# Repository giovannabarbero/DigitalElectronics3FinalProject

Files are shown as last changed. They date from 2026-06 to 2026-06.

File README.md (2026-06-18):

# Sistema de Medición de Nivel Sonoro - Sonómetro
> **Asignatura:** Electrónica Digital III - Universidad Nacional de Córdoba

> **Integrantes:**
> * Thomas von Büren - 43136697
> * Giovanna Luz Barbero - 46509956

> **Profesor:** Ing Marcos Blasco

---

## 🚀 1. Descripción General del Proyecto
Se toman mediciones del sonido ambiente mediante un micrófono, se procesa la información mediante estándares industriales aplicados a decibelímetros sonoros regulados, y se devuelve un valor en decibelios para ser expuesto mediante actuadores, indicadores visuales, e interfaces de comunicación. Posee un modo de auto-calibración.

### 🎯 Alcances del Proyecto 
* **El sistema SÍ es capaz de:** 
    * Adquirir información sonora ambiente en tiempo real.
    * Realizar cálculos de ponderación de curvas reguladas IEC 61672-1 y ANSI S1.43 sobre los datos obtenidos.
    * Calcular el valor en decibelios del sonido.
    * Mostrar valor y curva seleccionada en displays.
    * Mostrar el nivel en un Vu-Meter analógico y una tira ARGB LED NeoPixel.
    * Cambiar tau de adquisición y curva de ponderación *on the go*.
    * Inicializar modo de calibración para chequear correcta interpretación de valores ingresados.
    * Enviar String de información y recibir comandos mediante UART.
* **El sistema NO incluye (Fuera de alcance):** 
    * Almacenamiento local.
    * Portabilidad energética.
    * Conectividad por WiFi/Bluetooth/Ethernet.
    * Rigurosidad homologada ni certificada.

### ⏩ Posibles Etapas Siguientes 
* Migrar el circuito de protoboard a un circuito impreso (PCB) diseñado bajo normas de compatibilidad electromagnética (EMC).
* Implementar componente portable con batería para mejorar portabilidad.
* Emplear componentes especializados de mejor calidad y ad hoc al dispositivo

---

## 📐 2. Arquitectura del Sistema: Hardware y Software

### 🔌 Hardware & Interconexión
* **Diagrama de Bloques:**
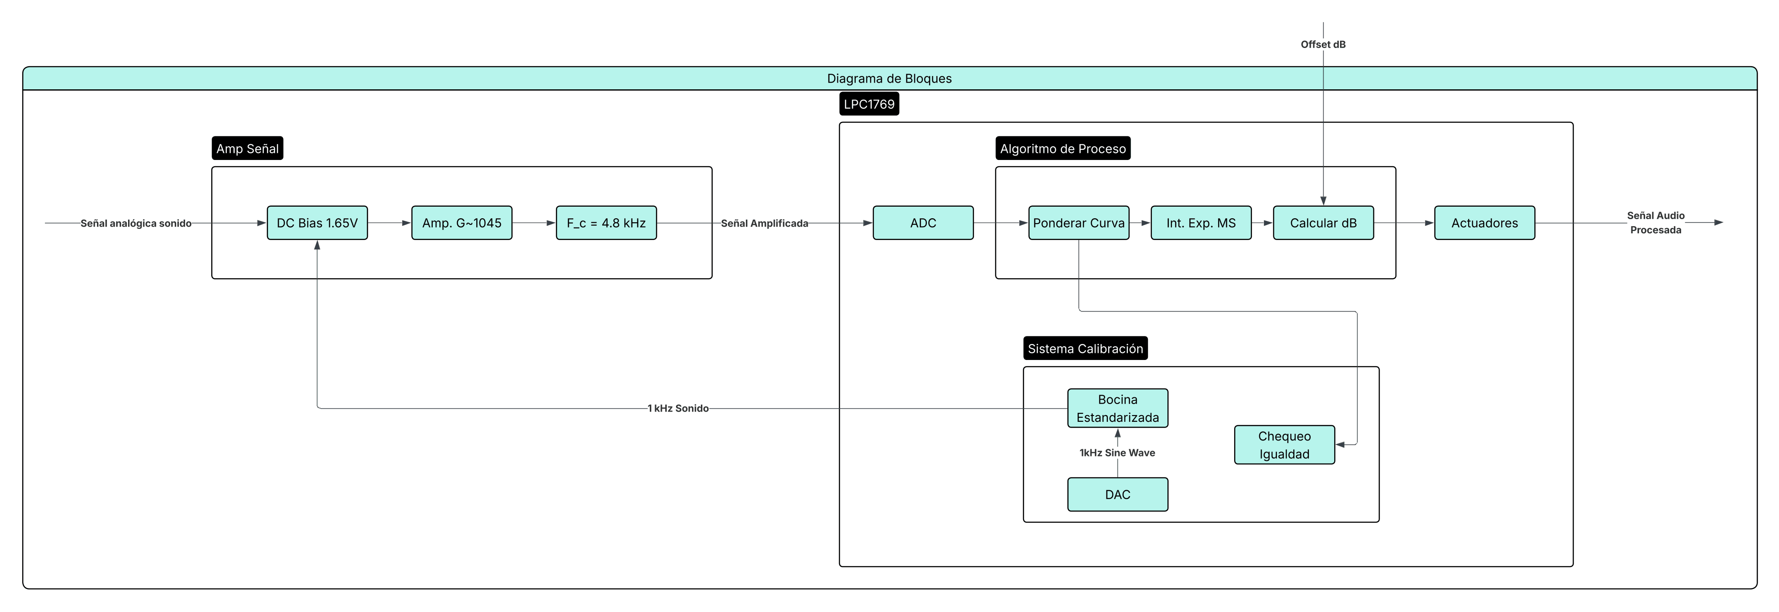
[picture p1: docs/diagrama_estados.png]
Máquina de Estados
  
* **Esquemático del Circuito:** 
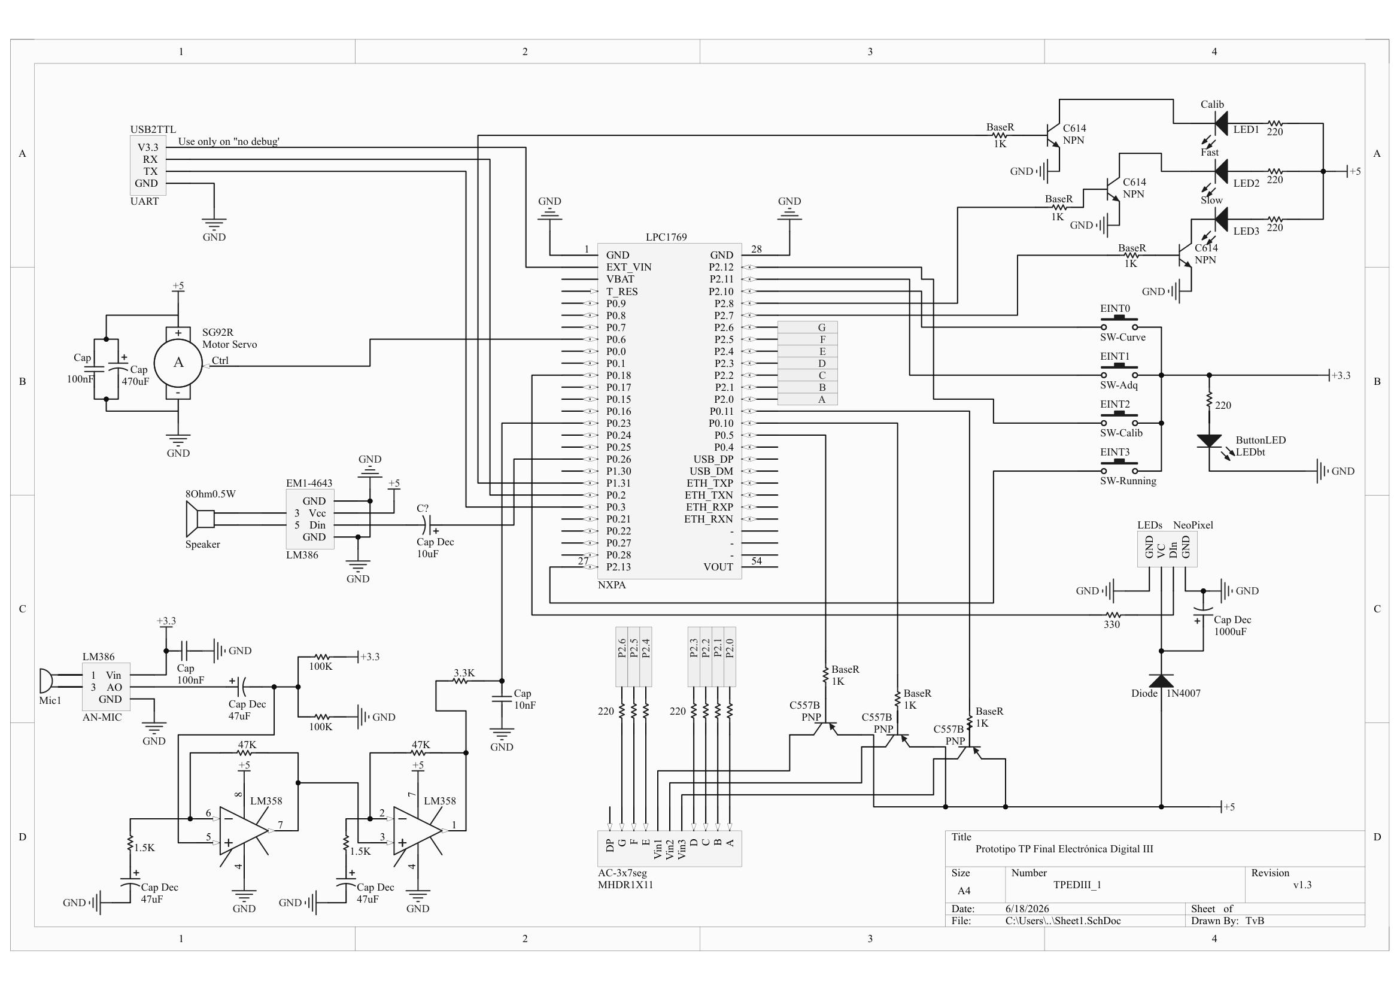
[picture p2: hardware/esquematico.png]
Esquemático Completo
  
* **Descripción del Circuito y Consideraciones de Diseño:** 
    * Pines de displays...
    * Diodo en Neopixel...
    * Decouple en bocina...
    * Botones y Led...
    * Decouple en Servo...
    * Amplificador de Micrófono:
        * Etapa bias y decouple... 
        * Etapa amp...
        * Etapa filtro...

### 💻 Arquitectura de Software (Firmware)
* **Diagrama de Flujo o Máquina de Estados:** 
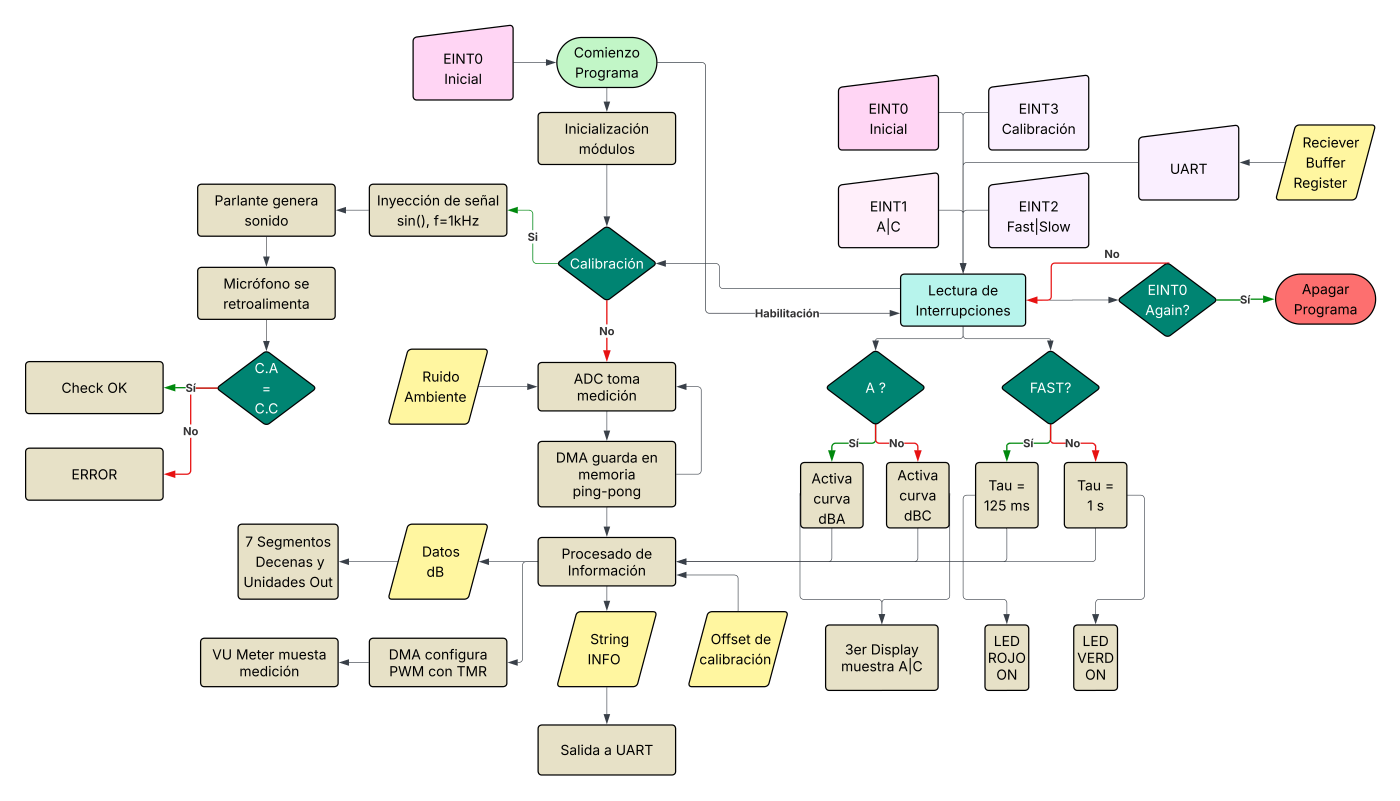
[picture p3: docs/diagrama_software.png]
Diagrama de Flujo / Máquina de Estados
  

---

## ⚡ 3. Especificaciones Eléctricas, Alimentación y Entorno

### 🔌 Parámetros de Alimentación y Consumo 
* **Tensión de operación del sistema:** 5V / 3.3V
* **Método de alimentación:** Fuente externa de 12V con regulador de voltaje lineal AMS1117-5V/3.3V / Alimentación por USB
* **Consumo estimado o medido:** * En modo activo (máxima carga, relés/motores encendidos): `~ 1500 mA`

### 📌 Cortex-M3 / ARM
* **IDE y SDK:** MCUXpresso IDE v25.6 con CMSISv2p00_LPC17xx
* **Microcontrolador Principal:** NXP LPC1769 Rev D.
* **Bibliotecas de Terceros y Versiones:** CMSIS-DSP; Drivers customizados por David Trujillo.
* **Periféricos Avanzados Utilizados:** NVIC, GPDMA, DAC, ADC, GPIO, TIMER, PWM, SPI-MOSI, UART.
* **Estrategia de Concurrencia:** Bare-metal con Máquina de Estados Cooperativa

---

## 🔄 4. Proceso de Integración y Desarrollo
Describan cronológicamente cómo fueron sumando y testeando las diferentes partes del proyecto (enfoque modular de ingeniería).

* **Etapa 1 (Validación inicial):**
     * Se realizaron investigaciones de la regulación de la medición del sonido en decibelios según la IEEE.
     * Se realizó el diagrama de estados correspondiente al flujo del código.
     * Se diseñó y cortó la madera donde se presentarían las mediciones finales.
* **Etapa 2 (Adquisición/Comunicación):** 
     * Se realizaron los diferentes bloques de código separadamente para así poder testear cada parte del proyecto por cuenta propia.
     * Se armaron los elementos bases del circuito (Módulo de micrófono, Parlante, Displays).
* **Etapa 3 (Integración lógica):** 
     * Se combinaron paulatinamente diferentes bloques para probar compatibilidad y facilitar el testing.
     * Se terminó de armar el circuito con todos los elementos integrados.
* **Etapa 4 (Sistema Completo):**
     * Se juntó todo el código para así probar el funcionamiento completo del proyecto.
     * Se soldaron componentes y se armó todo con el perfil de madera.

---

## 📊 5. Ensayos, Pruebas y Resultados 
Demuestren con datos empíricos que el sistema funciona correctamente. **Es obligatorio incluir registro visual**.

* **Pruebas Funcionales Realizadas:**
   * Medición de ganancia del micrófono: Se conectó la salida del amplificador operacional a un osciloscopio para confirmar la ganancia del módulo de micrófono y si el offset era el adecuado (1.65v en silencio).
   * Medición del nivel de decibelios del DAC: Se utilizó un decibelímetro para poder conseguir la medida homologada del sonido emitido por el parlante conectado al DAC, para así poder calibrar el medidor correctamente.
* **Evidencia Fotográfica y Gráficos:** 
   * 
  * *Foto del Prototipo Real:*
       * Medición de ganancia del osciloscopio:
         * Antes de ajustar el potenciómetro:
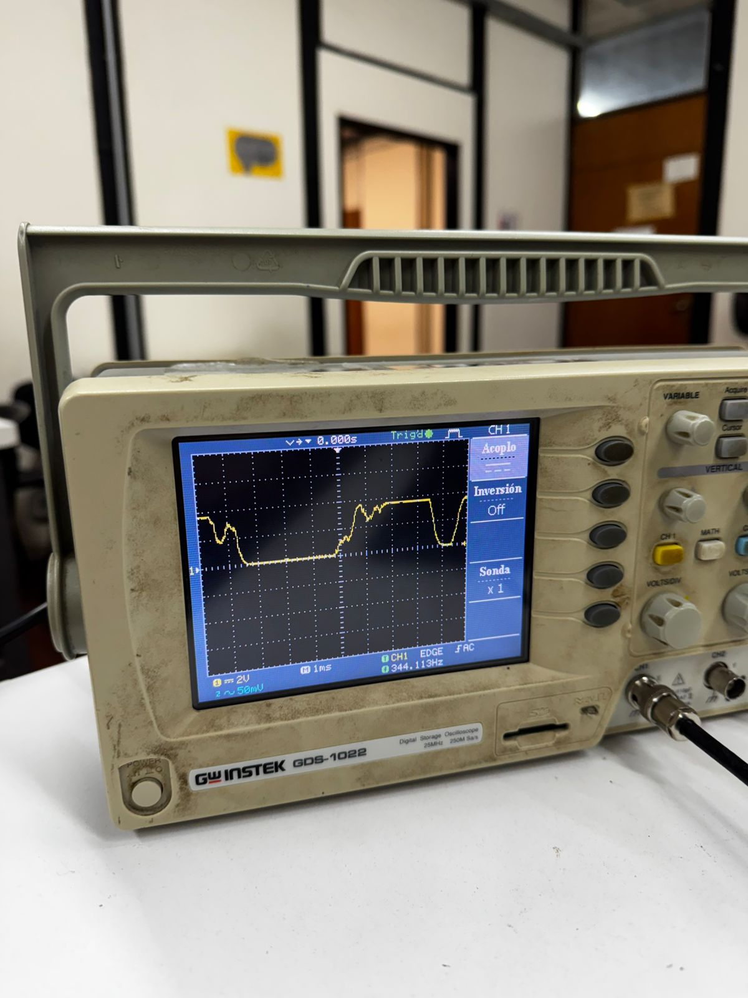
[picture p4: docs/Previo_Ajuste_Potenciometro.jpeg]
Sin potenciómetro ajustado
           
         * Luego de ajustar el potenciómetro:
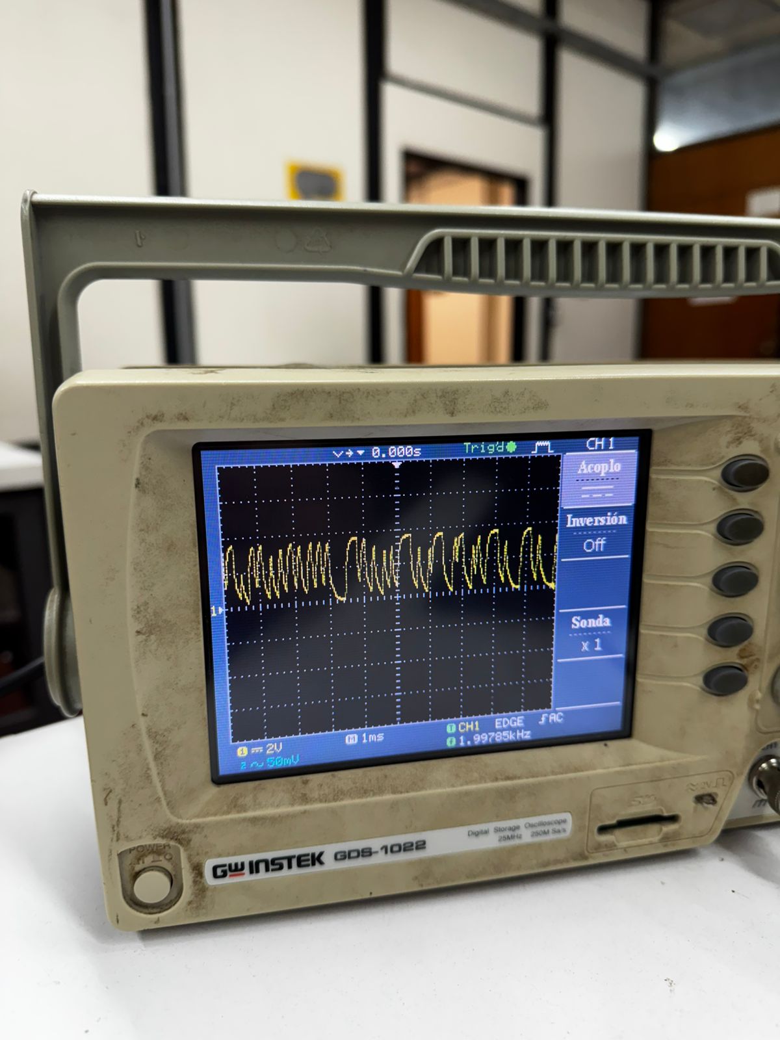
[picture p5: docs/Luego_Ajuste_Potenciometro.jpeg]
Potenciómetro ajustado
         
       * Foto del circuito funcionando:
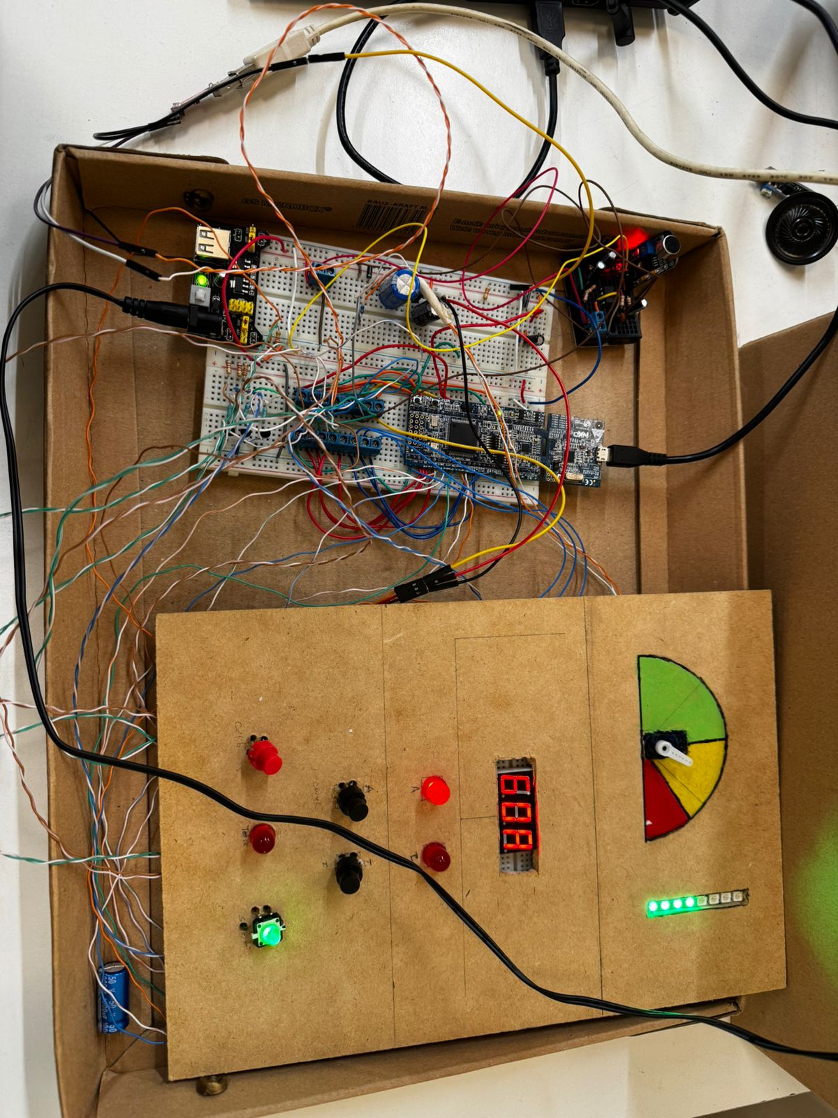
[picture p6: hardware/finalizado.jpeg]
Circuito finalizado
         

---

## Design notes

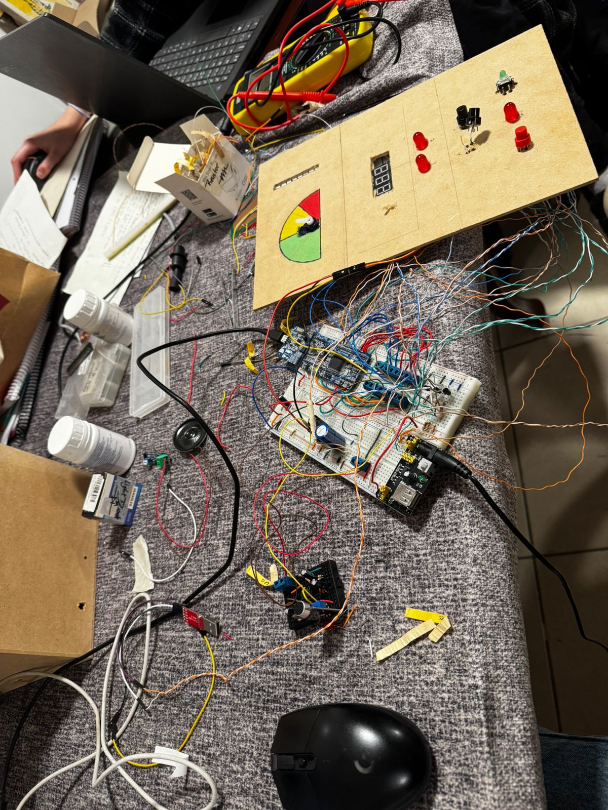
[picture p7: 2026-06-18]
docs/Fases de Desarrollo 3.jpeg

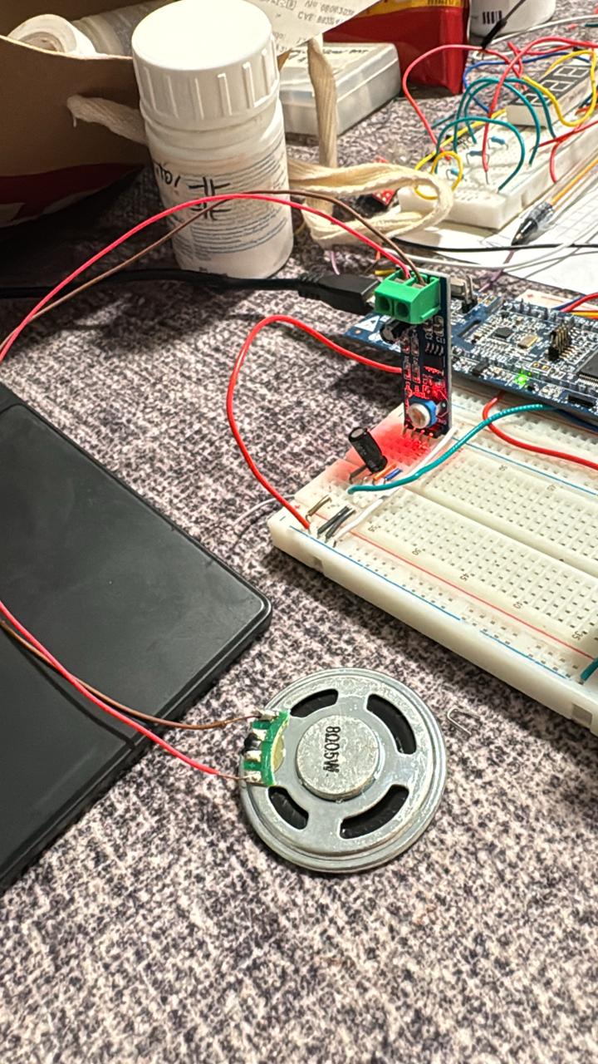
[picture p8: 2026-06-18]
docs/Bocina inicio.jpeg

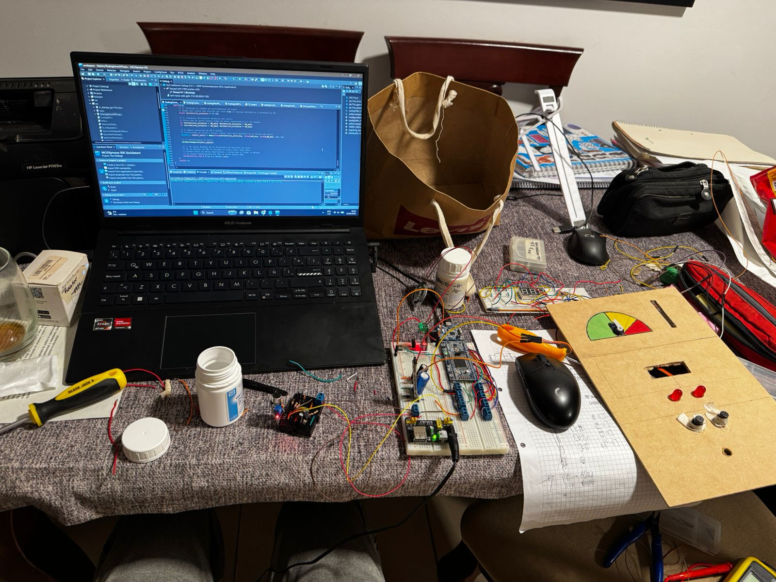
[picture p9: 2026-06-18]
docs/Fases de Desarrollo 2.jpeg

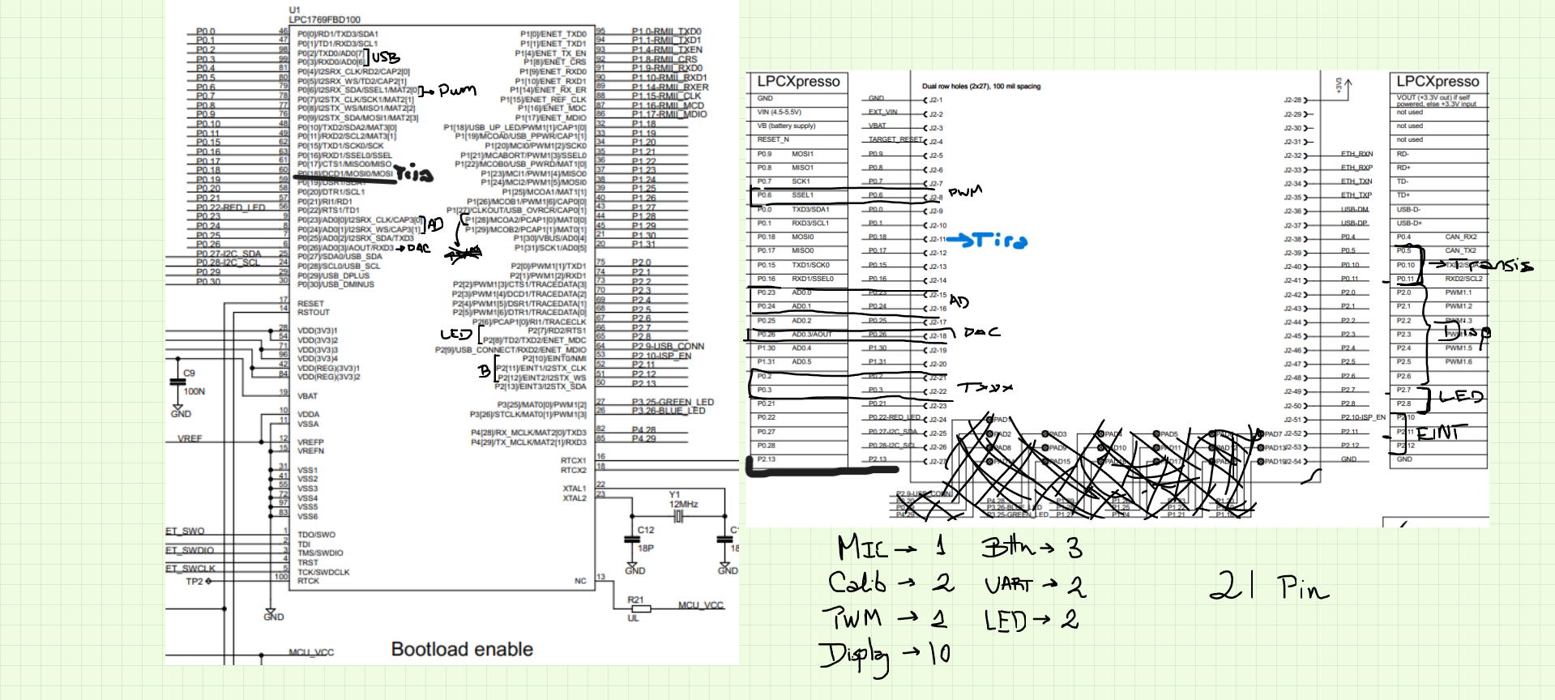
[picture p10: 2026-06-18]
docs/Drawing-2.sketchpad.png

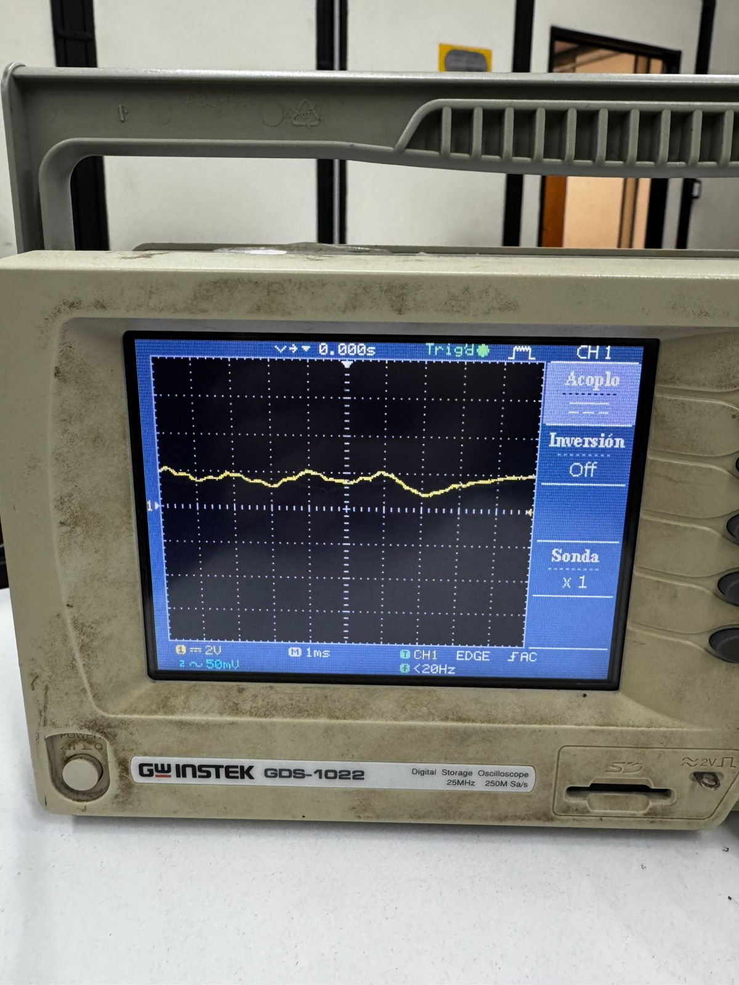
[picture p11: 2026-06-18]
docs/Silencio ambiente luego de ajustar potenciometro.jpeg

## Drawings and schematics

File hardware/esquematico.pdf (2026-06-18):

# LED3 GND VCDIn GND

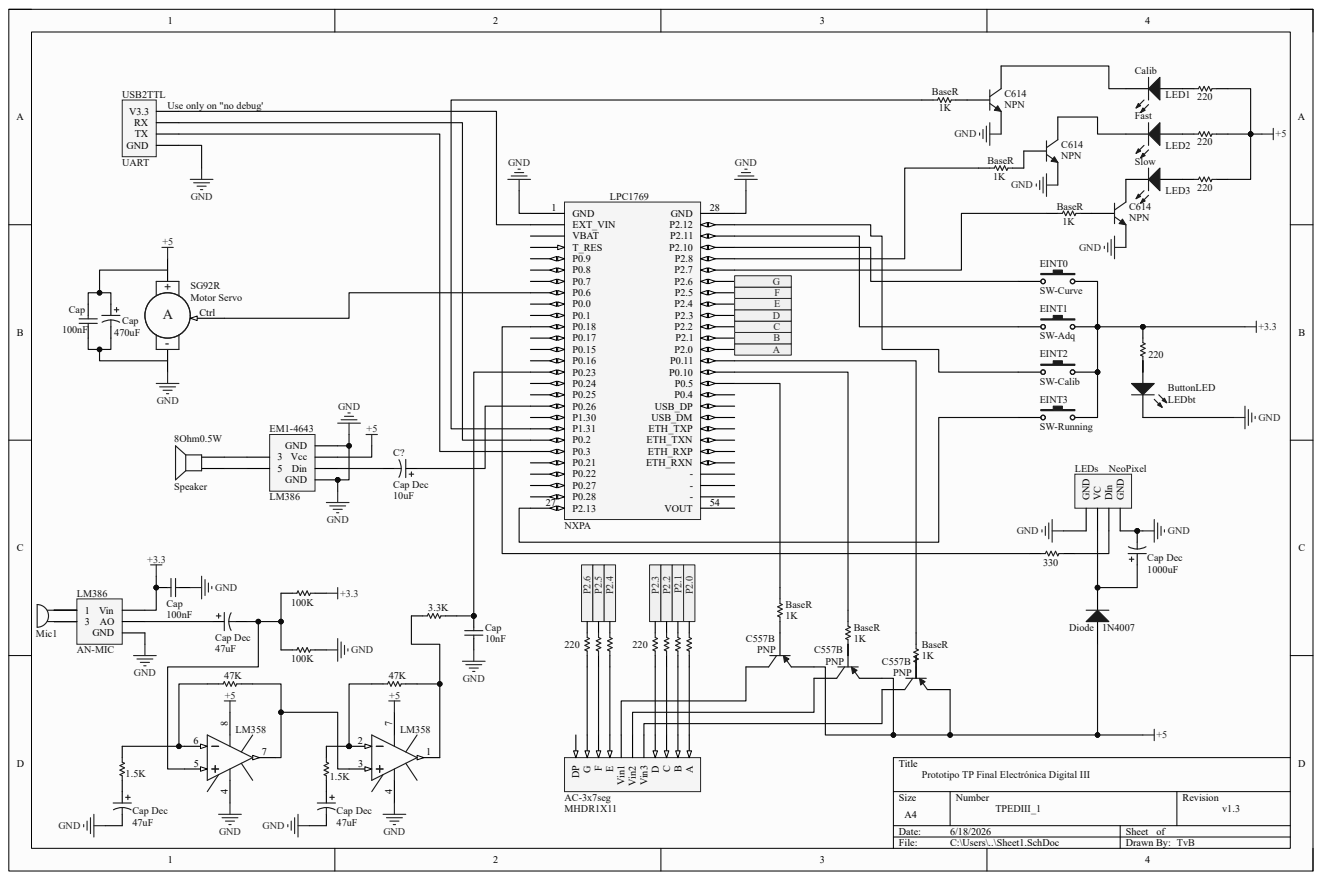
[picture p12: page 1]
Size; Number; Revision; Date:; Sheet of; File:; C:\Users\..\Sheet1.SchDoc; Drawn By:; GND 1; EXT_VIN VBAT T_RES P0.9 P0.8 P0.7 P0.6 P0.0 P0.1 P0.18 P0.17 P0.15 P0.16 P0.23 P0.24 P0.25 P0.26 P1.30 P1.31 P0.2 P0.3 P0.21 P0.22 P0.27 P0.28; VOUT; ETH_RXN; ETH_RXP; ETH_TXN; ETH_TXP; USB_DM; USB_DP; GND; NXPA; LPC1769; Diode; Ctrl; SG92R Motor Servo; PNP; 8Ohm0.5W; Speaker; Fast; LED2; Calib; LED1; Slow; LEDs NeoPixel; BA Vin1 Vin2 Vin3G FEDP; AC-3x7seg MHDR1X11; BaseR; Mic1; 1 Vin 3 AO GND; AN-MIC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

Use only on "no debug'

Title
Prototipo TP Final Electrónica Digital III

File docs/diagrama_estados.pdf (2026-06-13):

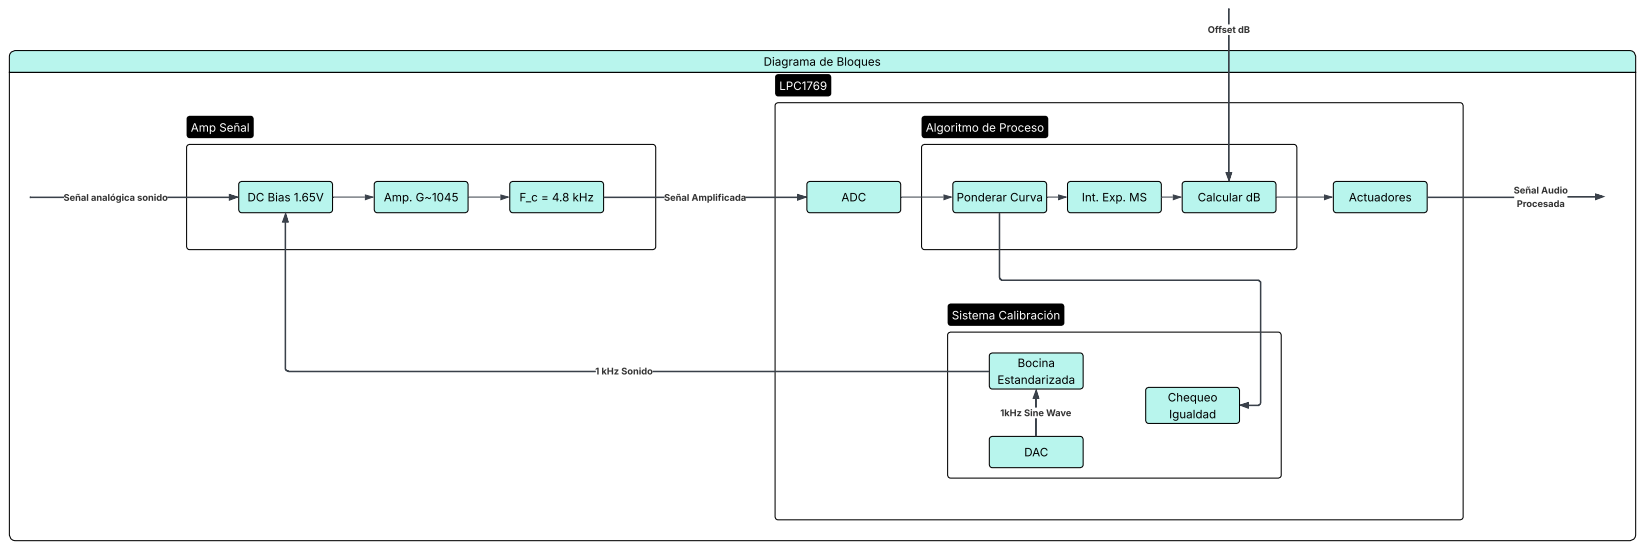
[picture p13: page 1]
Amp Señal; Algoritmo de Proceso; Sistema Calibración; Señal analógica sonido; DC Bias 1.65V; Amp. G~1045; F_c = 4.8 kHz; Señal Amplificada; ADC; Ponderar Curva; Int. Exp. MS; Calcular dB; Actuadores; Señal Audio Procesada; DAC; 1kHz Sine Wave; Bocina Estandarizada; 1kHz Sonido; Offset dB; Chequeo Igualdad

Diagrama de Bloques
LPC1769

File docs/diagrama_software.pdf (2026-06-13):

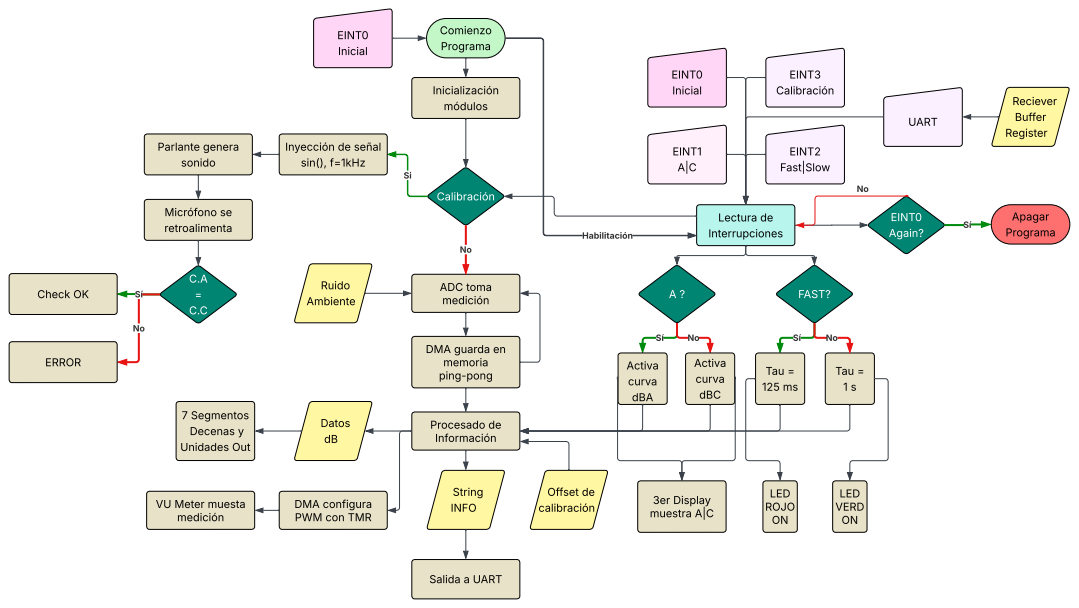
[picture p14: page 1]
Inicialización módulos; ADC toma medición; Procesado de Información; Salida a UART; Comienzo Programa; EINT0 Inicial; Ruido Ambiente; Lectura de Interrupciones; FAST?; Activa curva dBA; Activa curva dBC; Tau = 125 ms; Tau = 1 s; Habilitación; String; VU Meter muesta; INFO; medición; Datos dB; 7 Segmentos Decenas y Unidades Out; 3er Display muestra A|C; LED ROJO ON; LED VERD ON; EINT1 A|C; EINT2 Fast|Slow; EINT0 Again?; Apagar Programa; EINT3 Calibración; Calibración; Parlante genera sonido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

Inyección de señal
sin(), f=1kHz

DMA guarda en
memoria
ping-pong

DMA configura
PWM con TMR

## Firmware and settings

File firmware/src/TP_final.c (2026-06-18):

#include "LPC17xx.h"
#include <math.h> //log
#include "lpc17xx_timer.h"
#include "lpc17xx_gpio.h"
#include "lpc17xx_pinsel.h"
#include <stdlib.h>	//Para memoria
#include "lpc17xx_gpdma.h"
#include "lpc17xx_adc.h"
#include "lpc17xx_dac.h"
#include "lpc17xx_clkpwr.h"
#include "arm_math.h" //Funciones complejas
#include "lpc17xx_ssp.h"
#include "lpc17xx_exti.h"
#include "lpc17xx_uart.h"
#include <stdio.h>

//Defines Generales de math
#define BLOCK_SIZE 128
#define FS         24000.0f
#define TAU_FAST   0.125f
#define TAU_SLOW   1.0f
#define NUM_STAGES_A 3
#define NUM_STAGES_C 2
#define AHB_SRAM0 0x2007C000
//Mux
#define DEBOUNCE_TIME_MS 350
//Defines npxl
#define NUM_LEDS 8
#define BYTES_PER_LED 9
// Le devolvemos el +1 para que el último LED no se vuelva loco
#define SPI_BUFFER_SIZE ((NUM_LEDS * BYTES_PER_LED) + 1) // 72 bytes exactos
//Defines DAC
#define tabla_seno ((volatile uint32_t *) AHB_SRAM0)
const uint32_t valores_crudos[256] = {
		32768, 33600, 34368, 35200, 35968, 36800, 37568, 38336, 39168, 39936, 40704, 41472,
		42240, 43008, 43776, 44544, 45312, 46016, 46720, 47488, 48192, 48896, 49600, 50240,
		50944, 51584, 52224, 52864, 53504, 54144, 54720, 55296, 55872, 56448, 57024, 57536,
		58048, 58560, 59008, 59520, 59968, 60416, 60800, 61248, 61632, 61952, 62336, 62656,
		62976, 63296, 63552, 63808, 64064, 64256, 64512, 64704, 64832, 64960, 65088, 65216,
		65344, 65408, 65408, 65472, 65472, 65472, 65408, 65408, 65344, 65216, 65088, 64960,
		64832, 64704, 64512, 64256, 64064, 63808, 63552, 63296, 62976, 62656, 62336, 61952,
		61632, 61248, 60800, 60416, 59968, 59520, 59008, 58560, 58048, 57536, 57024, 56448,
		55872, 55296, 54720, 54144, 53504, 52864, 52224, 51584, 50944, 50240, 49600, 48896,
		48192, 47488, 46720, 46016, 45312, 44544, 43776, 43008, 42240, 41472, 40704, 39936,
		39168, 38336, 37568, 36800, 35968, 35200, 34368, 33600, 32768, 31936, 31168, 30336,
		29568, 28736, 27968, 27200, 26368, 25600, 24832, 24064, 23296, 22528, 21760, 20992,
		20224, 19520, 18816, 18048, 17344, 16640, 15936, 15296, 14592, 13952, 13312, 12672,
		12032, 11392, 10816, 10240, 9664, 9088, 8512, 8000, 7488, 6976, 6528, 6016,
		5568, 5120, 4736, 4288, 3904, 3584, 3200, 2880, 2560, 2240, 1984, 1728,
		1472, 1280, 1024, 832, 704, 576, 448, 320, 192, 128, 128, 64,
		64, 64, 128, 128, 192, 320, 448, 576, 704, 832, 1024, 1280,
		1472, 1728, 1984, 2240, 2560, 2880, 3200, 3584, 3904, 4288, 4736, 5120,
		5568, 6016, 6528, 6976, 7488, 8000, 8512, 9088, 9664, 10240, 10816, 11392,
		12032, 12672, 13312, 13952, 14592, 15296, 15936, 16640, 17344, 18048, 18816, 19520,
		20224, 20992, 21760, 22528, 23296, 24064, 24832, 25600, 26368, 27200, 27968, 28736,
		29568, 30336, 31168, 31936
};
#define LLI_ADDR (AHB_SRAM0 + (256 * 4))
#define listSin (*((volatile GPDMA_LLI_T *) LLI_ADDR))
//Defines UART
#define TX_SIZE 30
#define RX_SIZE 8
uint8_t uart_tx_buffer[TX_SIZE];
uint8_t uart_rx_buffer[RX_SIZE];
volatile uint8_t flag_rx_listo = 0;
volatile uint8_t flag_tx_listo = 1;
//Defines prom para lecturas
#define NUM_PROMEDIOS 4 // Promedia las 4 lecturas 4 segundos cada 1s
float32_t buffer_promedios[NUM_PROMEDIOS] = {0.0f};
uint8_t indice_promedio = 0;
// --- BUFFERS DMA ---
uint32_t buffer_ping[BLOCK_SIZE] __attribute__((aligned(4))); //Necesito que este bien alineada
uint32_t buffer_pong[BLOCK_SIZE] __attribute__((aligned(4)));
volatile GPDMA_LLI_T listPING __attribute__((aligned(4)));
volatile GPDMA_LLI_T listPONG __attribute__((aligned(4)));
volatile uint8_t flag_ping_listo = 0;
volatile uint8_t flag_pong_listo = 0;
//Variables de modos
volatile uint8_t curveMode = 0; // 0 = Curva A, 1 = Curva C
volatile uint8_t adqMode   = 0; // 0 = FAST, 1 = SLOW
volatile uint8_t running   = 0; // Empezamos apagado
volatile uint8_t calibMode = 0;
//Para displays
volatile uint32_t ticks_20ms = 0; // Para el antirrebote de los botones
volatile uint8_t c = 0;

//Variables Math
int32_t estados_A[3][4] = {0};
int32_t estados_C[2][4] = {0};
// --- VARIABLES DSP ---
/*float32_t coeficientes_A[15] = {
		    0.2441f,  0.4882f,  0.2441f, -0.2743f, -0.0156f,
		    1.0000f, -2.0000f,  1.0000f,  1.6502f, -0.7123f,
		    1.0000f, -2.0000f,  1.0000f,  1.8974f, -0.9021f
};*/
float32_t coeficientes_A[15] = {
    4.247708e-01f, 8.495416e-01f, 4.247708e-01f, -4.592981e-01f, -5.273868e-02f,
    1.000000e+00f, -2.000000e+00f, 1.000000e+00f, 1.796051e+00f, -8.009464e-01f,
    1.000000e+00f, -2.000000e+00f, 1.000000e+00f, 1.989243e+00f, -9.892723e-01f
};

float32_t estados_filtro_A[4 * NUM_STAGES_A];
arm_biquad_casd_df1_inst_f32 filtro_A;
/*
float32_t coeficientes_C[10] = {
    0.994628f, -1.989257f,  0.994628f,  1.989243f, -0.989272f,
    0.622000f,  1.244000f,  0.622000f, -1.154700f, -0.333300f
};*/

float32_t coeficientes_C[10] = {
    3.786953e-01f, 7.573906e-01f, 3.786953e-01f, -4.592981e-01f, -5.273868e-02f,
    1.000000e+00f, -2.000000e+00f, 1.000000e+00f, 1.989243e+00f, -9.892723e-01f
};

float32_t estados_filtro_C[4 * NUM_STAGES_C];
arm_biquad_casd_df1_inst_f32 filtro_C;
float32_t entrada_float[BLOCK_SIZE];
float32_t salida_filtro[BLOCK_SIZE];
float32_t senal_cuadrado[BLOCK_SIZE];
float32_t alpha;
float32_t uno_menos_alpha;
float32_t ms_anterior = 0.0f;
float32_t nivel_dc = 2048.0f; // Asumiendo centro en 1.65V
float32_t offset = 0.0f;      // Ajustar luego para calibrar con el sonómetro real ->Unused
// Variable global del reloj
volatile uint32_t msTicks = 0;
//neopxl
int ledsaencender = 0;
uint8_t spi_buffer[SPI_BUFFER_SIZE];
// Variables UART para ver en TIMER2
volatile uint32_t contador_bloques = 0;
volatile float32_t nivel_dB_mostrar = 0.0f;
volatile uint8_t dato_dB_nuevo = 0;

// Protos

void ConfigurarReloj100MHz_FuerzaBruta(void);
void configButton(void);
void configLED(void);

void configDMA_ADCpp(void);
void configADC(void);
void actualizarAlpha(void);
float32_t calibrar_lectura_dB(float32_t db_crudo);

void configDMA_DAC(void);
void configDAC(void);
void initDMA(void);
void cargarValoresSin(void);

void configTMR1_PWM(void);
void setServoAngle(uint16_t angle);
void moverServoPorDb(int dB_actual);

void carga_dB_NeoPixel(float nivel_dB);
void Set_LED_Color(int led_index, uint8_t g, uint8_t r, uint8_t b);
void enviar_NeoPixel_Rapido(void);
void Configurar_SSP0_NeoPixel(void);
int Calcular_Leds_Desde_dB(float valor_dB);

void Configurar_Timer0_Retardos(void);
void Delay_us(uint32_t us);
void Delay_ms(uint32_t ms);

void configPIN_disp(void);
uint8_t DecADisp(uint8_t);
void configTMR2(void);
volatile int PDdisplay; //Variables Disp
volatile int PEdisplay;

void turnOffButtons(void);
void turnOnButtons(void);

void Configurar_UART0(void);
void EnviarString_DMA(char* texto);
void ConfigurarRX_DMA(void);

void apagar_DAC_pin(void);
void encender_DAC_pin(void);

int main() {
	cargarValoresSin();
	LPC_SC->PCONP |= (1 << 26); // DAC
	LPC_SC->PCONP |= (1 << 29); // GPDMA
    LPC_SC->FLASHCFG = (LPC_SC->FLASHCFG & ~0x0000F000) | (4 << 12);//Proteger Flash y subir a 100 MHz (Necesario)
    ConfigurarReloj100MHz_FuerzaBruta();

    configTMR1_PWM();
    Configurar_Timer0_Retardos();
    Configurar_SSP0_NeoPixel();
    configADC();
    configDMA_ADCpp();
	//configDAC();
	//configDMA_DAC();
	//GPDMA_ChannelStart(GPDMA_CH_1); -->Pasados a calivb
    configPIN_disp();
    configTMR2();
    TIM_Enable(LPC_TIM2);
    Configurar_UART0();
    ConfigurarRX_DMA();
    configLED();     // LEDs de modo FAST/SLOW y calibración
    configButton();  // EINT0-3
    //apagar npxl
    for(int i=0; i<NUM_LEDS; i++) Set_LED_Color(i, 0, 0, 0);
    enviar_NeoPixel_Rapido();

    // Inicializar Filtro A y Filtro C siempre al inicio
    arm_biquad_cascade_df1_init_f32(&filtro_A, NUM_STAGES_A, coeficientes_A, estados_filtro_A);
    arm_biquad_cascade_df1_init_f32(&filtro_C, NUM_STAGES_C, coeficientes_C, estados_filtro_C);
    curveMode = 0;       // Aseguramos
    adqMode = 0;         // Aseguramos
    actualizarAlpha();

    uint32_t *buffer_a_procesar = NULL;
    contador_bloques = 0; // global

while(1){
    while(running){
    	if (calibMode) {
    		//Inicio DAC
    		LPC_SC->PCONP |= (1 << 26);
    		encender_DAC_pin();
    		configDAC();
    		configDMA_DAC();

    		GPIO_SetPins(1, (1U << 31)); //LED
    		turnOffButtons(); //Bloq

			// Apago npxl y dsp
			for(int i=0; i<NUM_LEDS; i++) Set_LED_Color(i, 0, 0, 0);
			enviar_NeoPixel_Rapido();
			PDdisplay = 0;
			PEdisplay = 0;

			// Servo a 0° (El mínimo ruido calibrado es maso 13 dB)
			moverServoPorDb(13);

			//Iniciar el DAC
			GPDMA_ChannelStart(GPDMA_CH_1);

			uint8_t calibrado = 0;
			uint8_t error_calib = 0; // <- Flag de error solicitada
			uint8_t intentos = 0;    // <- Contador de intentos (5)
			uint32_t *buffer_calib = NULL;

			// Variables temporales
			float32_t salida_A[BLOCK_SIZE], salida_C[BLOCK_SIZE];
			float32_t senal_cuad_A[BLOCK_SIZE], senal_cuad_C[BLOCK_SIZE];
			float32_t ms_ant_A = ms_anterior, ms_ant_C = ms_anterior;
			uint32_t contador_calib = 0;

			//Bucle de calibración: Adquirir hasta que se calibre o falle 5 veces
			while (!calibrado && !error_calib) {
				// Chequear disponibilidad de buffer DMA del ADC
				if (flag_ping_listo) {
					flag_ping_listo = 0;
					buffer_calib = buffer_ping;
				} else if (flag_pong_listo) {
					flag_pong_listo = 0;
					buffer_calib = buffer_pong;
				}
				if (buffer_calib != NULL) {
					// Remover bias DC
					for (uint32_t i = 0; i < BLOCK_SIZE; i++) {
						uint32_t adc_raw = (buffer_calib[i] >> 4) & 0xFFF;
						entrada_float[i] = ((float32_t)adc_raw) - nivel_dc;
					}
					// Filtrar en paralelo (Curva A y Curva C)
					arm_biquad_cascade_df1_f32(&filtro_A, entrada_float, salida_A, BLOCK_SIZE);
					arm_biquad_cascade_df1_f32(&filtro_C, entrada_float, salida_C, BLOCK_SIZE);
					// Elevar al cuadrado
					arm_mult_f32(salida_A, salida_A, senal_cuad_A, BLOCK_SIZE);
					arm_mult_f32(salida_C, salida_C, senal_cuad_C, BLOCK_SIZE);
					// Integración Exponencial RMS
					float32_t ms_A = 0.0f, ms_C = 0.0f;
					for (uint32_t i = 0; i < BLOCK_SIZE; i++) {
						ms_A = (alpha * senal_cuad_A[i]) + (uno_menos_alpha * ms_ant_A);
						ms_ant_A = ms_A;

						ms_C = (alpha * senal_cuad_C[i]) + (uno_menos_alpha * ms_ant_C);
						ms_ant_C = ms_C;
					}

					contador_calib++;
					buffer_calib = NULL;

					// Mostrar e inspeccionar resultados cada ~1 segundo (~187 bloques) si 1blq = Muestras/MPS = 5.33 mseg, cant blq = 1s / 5.33ms
					if (contador_calib >= 187) {
						contador_calib = 0;
						intentos++; // Incrementamos el intento en cada segundo transcurrido

						float32_t db_A_crudo = 0.0f, db_C_crudo = 0.0f;

						if (ms_A > 0.0001f) db_A_crudo = 10.0f * log10f(ms_A);
						if (ms_C > 0.0001f) db_C_crudo = 10.0f * log10f(ms_C);

						// Aplicar corrección final de Hardware
						float32_t db_A = calibrar_lectura_dB(db_A_crudo);
						float32_t db_C = calibrar_lectura_dB(db_C_crudo);

						//printf("Intento %d/5 - Curva A: %.2f dB | Curva C: %.2f dB\n", intentos, db_A, db_C);
						//fflush(stdout);

						// Chequear Condiciones (Misma onda con tolerancia de 1dB y rango entre 90 y 95)
						if (fabs(db_A - db_C) <= 1.0f && (db_A >= 90.0f && db_A <= 95.0f)) {
							//printf("¡Calibracion Exitosa!\n");
							calibrado = 1;
						}
						// Max intentos entonces err
						else if (intentos >= 5) {
							//printf("Error: No se pudo calibrar tras 5 intentos.\n");
							//fflush(stdout);
							error_calib = 1;
						}
					}
				}
			}

			// Caso error
			if (error_calib) {
				// PRINT EE
				PDdisplay = 11;
				PEdisplay = 11;

				// Bloqueo para ver EE
				for (volatile uint32_t i = 0; i < 24000000; i++);
				error_calib = 0;
			}

			// Fin calib, vuelvo a comun
			calibMode = 0;
			GPIO_ClearPins(1, (1U << 31));
			// Apagamos el funcionamiento del DAC
			GPDMA_ChannelStop(GPDMA_CH_1);
			LPC_DAC->DACR = 0;
			apagar_DAC_pin();
			GPIO_SetDir(0, (1 << 26), 1);
			GPIO_ClearPins(0, (1 << 26));
			LPC_SC->PCONP &= ~(1 << 26);
			// Reactivamos los botones llamando a la función
			turnOnButtons();
    	}
    	else //	NORMAL
    	{
    	//Recepcion ordenes UART
		if (flag_rx_listo) {
			flag_rx_listo = 0;
			if (strncmp((char*)uart_rx_buffer, "SETMODOA", 8) == 0) curveMode = 0;
			else if (strncmp((char*)uart_rx_buffer, "SETMODOC", 8) == 0) curveMode = 1;
			else if (strncmp((char*)uart_rx_buffer, "SETVEL_F", 8) == 0) { adqMode = 0; actualizarAlpha(); }
			else if (strncmp((char*)uart_rx_buffer, "SETVEL_S", 8) == 0) { adqMode = 1; actualizarAlpha(); }
			else if (strncmp((char*)uart_rx_buffer, "FAILBTTN", 8) == 0) { turnOffButtons(); }
			else if (strncmp((char*)uart_rx_buffer, "RETUBTTN", 8) == 0) { turnOnButtons(); }

			ConfigurarRX_DMA();
			//GPDMA_ChannelStart(GPDMA_CH_4); -> empezarlo en la DMA directo
		}
    	// Check buffer
		if (flag_ping_listo) {
			flag_ping_listo = 0;
			buffer_a_procesar = buffer_ping;
		} else if (flag_pong_listo) {
			flag_pong_listo = 0;
			buffer_a_procesar = buffer_pong;
		}
		//Procesamos audio
		if (buffer_a_procesar != NULL) {
			// Caast a float y elimino bias DC
			for (uint32_t i = 0; i < BLOCK_SIZE; i++) {
				uint32_t adc_raw = (buffer_a_procesar[i] >> 4) & 0xFFF;
				entrada_float[i] = ((float32_t)adc_raw) - nivel_dc;
			}
			if(curveMode){
			arm_biquad_cascade_df1_f32(&filtro_C, entrada_float, salida_filtro, BLOCK_SIZE);}
			else {
			arm_biquad_cascade_df1_f32(&filtro_A, entrada_float, salida_filtro, BLOCK_SIZE);
			}
			// sqrt
			arm_mult_f32(salida_filtro, salida_filtro, senal_cuadrado, BLOCK_SIZE);
			//actualizarAlpha();//pasar a el cambio directo en eint
			// D. Integración Exponencial (Fast RMS)
			float32_t valor_MS_actual = 0.0f;

			for (uint32_t i = 0; i < BLOCK_SIZE; i++) {
				valor_MS_actual = (alpha * senal_cuadrado[i]) + (uno_menos_alpha * ms_anterior);
				ms_anterior = valor_MS_actual;
			}
			//Imprimir resultados 1 vez por segundo (~187 bloques) si 1blq = Muestras/MPS = 5.33 mseg, cant blq = 1s / 5.33ms
			contador_bloques++;
			if (contador_bloques >= 187) {
				contador_bloques = 0;

				// 1. Calculamos el nivel crudo
				float32_t nivel_dB_crudo = 0.0f;
				if (valor_MS_actual > 0.0001f) {
				    nivel_dB_crudo = 10.0f * log10f(valor_MS_actual);
				}

				// LIMITAMOS EL RANGO (Esto evita el crash por valores fuera de tabla)
				if (curveMode == 1) {
									nivel_dB_crudo = nivel_dB_crudo - 11.0f; // <--- Restamos el exceso
								}

				//llamamos a tu función de calibración
				float32_t nivel_dB_final = calibrar_lectura_dB(nivel_dB_crudo);

				// MOVING AVERAGE
				//buffer rápido para evitar arrancar en 0
				if (buffer_promedios[0] == 0.0f) {
					for(int i=0; i<NUM_PROMEDIOS; i++) buffer_promedios[i] = nivel_dB_final;
				}

				buffer_promedios[indice_promedio] = nivel_dB_final;
				indice_promedio = (indice_promedio + 1) % NUM_PROMEDIOS;

				float32_t suma_promedio = 0.0f;
				for(int i = 0; i < NUM_PROMEDIOS; i++) {
					suma_promedio += buffer_promedios[i];
				}

				nivel_dB_mostrar = suma_promedio / NUM_PROMEDIOS; //promedio de 4
				dato_dB_nuevo = 1; // Avisar a TIMER2_IRQHandler que hay un dato fresco para UART

				// Formateo para imprimir con int usando prom
				int parte_entera  = (int)nivel_dB_mostrar;
				int parte_decimal = (int)((nivel_dB_mostrar - (float32_t)parte_entera) * 100.0f);
				if (parte_decimal >= 100) {
					parte_decimal = 0;
					parte_entera++;
				}

				//char* modo_curva = (curveMode == 0) ? "A" : "C";
				//char* modo_adq   = (adqMode   == 0) ? "FAST" : "SLOW";

				// Imprimir resultados con la etiqueta dinámica
				//printf("Nivel de Ruido [%s/%s]: %d.%02d dB\n", modo_curva, modo_adq, parte_entera, parte_decimal);
				//fflush(stdout);

				int valor_display = parte_entera;
				if (valor_display > 99) {
					valor_display = 99;
				}

				PDdisplay = valor_display / 10;
				PEdisplay = valor_display % 10;

				moverServoPorDb(parte_entera);// Servo directamente se actualiza al actualizar valor
				//Delay_ms(50);
				carga_dB_NeoPixel(parte_entera);
				//Delay_ms(20);
			    if(adqMode == 0) { // FAST
			        GPIO_SetPins(2, (1U << 8));   // Encender LED FAST (P2.8)
			        GPIO_ClearPins(2, (1U << 7)); // Apagar  LED SLOW (P0.7)
			    } else { // SLOW
			        GPIO_ClearPins(2, (1U << 8)); // Apagar  LED FAST
			        GPIO_SetPins(2, (1U << 7));   // Encender LED SLOW
			    }
			}
			// Liberamos el buffer para el DMA
			buffer_a_procesar = NULL;
			}
    	}
    }
	//termina el while running
}
    return 0;
}

void actualizarAlpha(void){
    if(adqMode){
        alpha = 1.0f - expf(-1.0f / (FS * TAU_SLOW));
        uno_menos_alpha = 1.0f - alpha;
    } else {
        alpha = 1.0f - expf(-1.0f / (FS * TAU_FAST));
        uno_menos_alpha = 1.0f - alpha;
    }
}

void configADC(void) {
    LPC_SC->PCONP |= (1 << 12);
    ADC_PowerUp();
    ADC_Init(24000);
    ADC_PinConfig(ADC_CHANNEL_0);
    ADC_ChannelEnable(ADC_CHANNEL_0);
    ADC_BurstEnable();
    ADC_StartCmd(ADC_START_CONTINUOUS);
}

void configDMA_ADCpp(void) {
    LPC_SC->PCONP |= (1 << 29);
    LPC_GPDMA->DMACConfig = 0x01;
    GPDMA_Init();

    uint32_t controlADCPP = (BLOCK_SIZE & 0xFFF)|(2 << 18)|(2 << 21)|(1 << 27)|(1U << 31);

    listPING.control = controlADCPP;
    listPING.nextLLI = (uint32_t)&listPONG;
    listPING.dstAddr = (uint32_t)buffer_ping;
    listPING.srcAddr = (uint32_t)(&LPC_ADC->ADDR0);

    listPONG.control = controlADCPP;
    listPONG.nextLLI = (uint32_t)&listPING;
    listPONG.dstAddr = (uint32_t)buffer_pong;
    listPONG.srcAddr = (uint32_t)(&LPC_ADC->ADDR0);

    GPDMA_Channel_CFG_T ConADC;
    GPDMA_Endpoint_T S1, D1;
    S1.increment = DISABLE; S1.width = GPDMA_WORD; S1.burst = GPDMA_BSIZE_1;
    D1.increment = ENABLE;  D1.width = GPDMA_WORD; D1.burst = GPDMA_BSIZE_1;

    ConADC.channelNum = 0;
    ConADC.transferSize = BLOCK_SIZE;
    ConADC.type = GPDMA_P2M;
    ConADC.srcMemAddr = 0;
    ConADC.dstMemAddr = (uint32_t)buffer_ping;
    ConADC.srcConn = GPDMA_ADC;
    ConADC.dstConn = (GPDMA_CONNECTION)0;
    ConADC.src = S1;
    ConADC.dst = D1;
    ConADC.intTC = ENABLE;
    ConADC.intErr = DISABLE;
    ConADC.linkedList = (uint32_t)&listPONG;

    GPDMA_SetupChannel(&ConADC);
    NVIC_EnableIRQ(DMA_IRQn);
    GPDMA_ChannelStart(GPDMA_CH_0);
}

void DMA_IRQHandler(void) {
    static uint8_t turno_ping = 1;

    // Canal 0: ADC (ping/pong)
    if (GPDMA_IntGetStatus(GPDMA_INTTC, GPDMA_CH_0) == SET) {
        GPDMA_ClearIntPending(GPDMA_CLR_INTTC, GPDMA_CH_0);
        if (turno_ping) { flag_ping_listo = 1; turno_ping = 0; }
        else            { flag_pong_listo = 1; turno_ping = 1; }
    }

    // 1 lo usa DAC

    // 2 lo iba a usar npxl

    // Canal 3: UART TX
    if (GPDMA_IntGetStatus(GPDMA_INTTC, GPDMA_CH_3) == SET) {
        GPDMA_ClearIntPending(GPDMA_CLR_INTTC, GPDMA_CH_3);
        flag_tx_listo = 1;
    }

    // Canal 4: UART RX
    if (GPDMA_IntGetStatus(GPDMA_INTTC, GPDMA_CH_4) == SET) {
        GPDMA_ClearIntPending(GPDMA_CLR_INTTC, GPDMA_CH_4);
        flag_rx_listo = 1;
    }
}

void cargarValoresSin(void){
	for (int i = 0; i < 256; i++) {
	    tabla_seno[i] = valores_crudos[i];
	}
}

void configDAC(void){
	CLKPWR_SetPCLKDiv(CLKPWR_PCLKSEL_DAC, CLKPWR_PCLKSEL_CCLK_DIV_4);

	DAC_CONVERTER_CFG_T DAC;
	DAC.dmaCounter   = ENABLE;
	DAC.dmaRequest   = ENABLE;
	DAC.doubleBuffer = DISABLE;

	DAC_Init();
	DAC_ConfigDAConverterControl(&DAC);
	DAC_SetBias(DAC_700uA);
	DAC_SetDMATimeOut(96); // 3.9uS a CClock 100MHz -> 1.00673 kHz
}

void configDMA_DAC(void){
	listSin.srcAddr = (uint32_t) AHB_SRAM0;
	listSin.dstAddr = (uint32_t) &(LPC_DAC->DACR);
	listSin.nextLLI = (uint32_t) &listSin;
	listSin.control = GPDMA_DMACCxControl_TransferSize(256)
	                 | GPDMA_DMACCxControl_SWidth(GPDMA_WORD)
	                 | GPDMA_DMACCxControl_DWidth(GPDMA_WORD)
	                 | GPDMA_DMACCxControl_SI;

	GPDMA_Channel_CFG_T Con;
	GPDMA_Endpoint_T S, D;

	S.increment = ENABLE;
	S.width     = GPDMA_WORD;
	S.burst     = GPDMA_BSIZE_1;

	D.increment = DISABLE;
	D.width     = GPDMA_WORD;
	D.burst     = GPDMA_BSIZE_1;

	Con.channelNum  = GPDMA_CH_1;
	Con.transferSize = 256;
	Con.type        = GPDMA_M2P;
	Con.srcMemAddr  = AHB_SRAM0;
	Con.dstMemAddr  = (uint32_t) &(LPC_DAC->DACR);
	Con.srcConn     = (GPDMA_CONNECTION) 0;
	Con.dstConn     = GPDMA_DAC;
	Con.src = S;
	Con.dst = D;
	Con.intTC  = DISABLE;
	Con.intErr = DISABLE;
	Con.linkedList = (uint32_t) &listSin;

	GPDMA_SetupChannel(&Con);
}

void ConfigurarReloj100MHz_FuerzaBruta(void) {
    LPC_SC->CLKSRCSEL = 0x00;
    LPC_SC->PLL0CON   = 0x00;
    LPC_SC->PLL0FEED  = 0xAA;
    LPC_SC->PLL0FEED  = 0x55;

    LPC_SC->FLASHCFG = (LPC_SC->FLASHCFG & ~0x0000F000) | (4 << 12);

    LPC_SC->SCS       = 0x20;
    while ((LPC_SC->SCS & 0x40) == 0);

    LPC_SC->CLKSRCSEL = 0x01;
    LPC_SC->PLL0CFG   = 0x00010018;
    LPC_SC->PLL0FEED  = 0xAA;
    LPC_SC->PLL0FEED  = 0x55;
    LPC_SC->PLL0CON   = 0x01;
    LPC_SC->PLL0FEED  = 0xAA;
    LPC_SC->PLL0FEED  = 0x55;
    while ((LPC_SC->PLL0STAT & (1 << 26)) == 0);
    LPC_SC->CCLKCFG   = 2;
    LPC_SC->PLL0CON   = 0x03;
    LPC_SC->PLL0FEED  = 0xAA;
    LPC_SC->PLL0FEED  = 0x55;
    SystemCoreClock = 100000000;
}
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

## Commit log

2026-06-07 Update
    Actualizando main de a poco
2026-06-13 Actualizo README.md con el diagrama de estados y el diagrama de software. Agrego los archivos del hardware, incluyendo el esquemático y los archivos de Altium.
    [Schlib1.SchLib, Sheet1.SchDoc]
2026-06-18 Update Schematic
    [Sheet1.SchDoc]
2026-06-18 DOCS
    EE de desarrollo
2026-06-18 Update TP_final.c
    Cambios TP_final fix/ change coef
    [TP_final.c]
2026-06-18 circuito finalizado photo
